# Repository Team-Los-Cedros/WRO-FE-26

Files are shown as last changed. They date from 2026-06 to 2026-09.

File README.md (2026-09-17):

# Proyecto Future Engineers - Team Los Cedros (WRO 2026)

Bienvenidos al repositorio oficial del **Team Los Cedros**, integrado por estudiantes del Colegio Los Cedros en Valera, Estado Trujillo, Venezuela. Aquí compartimos la documentación técnica, diseños de hardware, esquemas eléctricos y el software modular de nuestro vehículo autónomo para la World Robot Olympiad (WRO) 2026.

<p align="center">
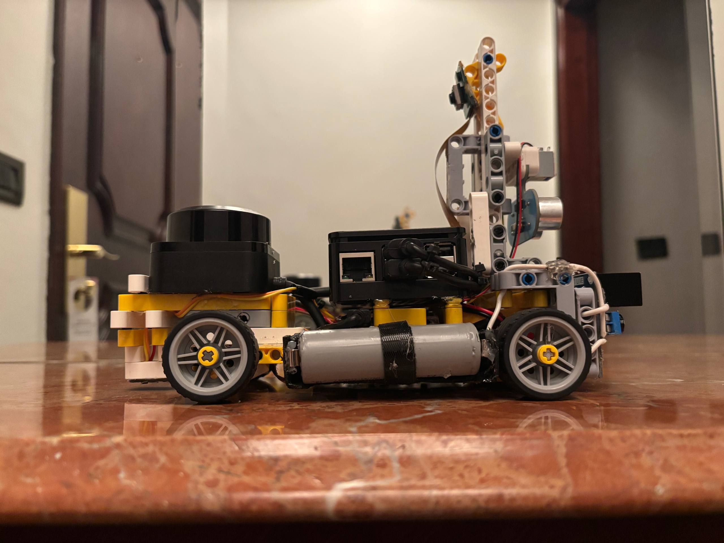
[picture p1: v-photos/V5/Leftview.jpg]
Vehiculo autonomo del Team Los Cedros, perfil izquierdo
  
</p>

---

## El robot en una página

#### Primero, en palabras simples

Es un **coche del tamaño de una hoja de papel que se conduce solo**. Hay que dejarlo en una pista cuadrada con paredes, apretarle un botón y alejarse: a partir de ahí nadie lo toca. Tiene que dar tres vueltas sin rozar las paredes y, en la prueba difícil, esquivar unos bloques de colores —**el rojo se pasa por la derecha y el verde por la izquierda**—, y al final volver a aparcar donde empezó.

Para lograrlo necesita tres cosas, que son las mismas que necesita una persona conduciendo: **ver** dónde está, **decidir** hacia dónde ir y **mover** el volante y el acelerador. Este documento explica cómo hace cada una de las tres, y —más importante— **cómo comprobamos que de verdad las hace**, porque casi todo lo que aquí se afirma tiene detrás una medición, no una suposición.

#### Y ahora, en términos técnicos

Un coche autónomo de **242 x 138 mm y 720 g** sobre chasis LEGO Technic, con dirección Ackermann. Lo gobiernan **dos cerebros**: una Raspberry Pi 5 que decide (visión, LiDAR y máquina de estados) y una Pico 2 que ejecuta con puntualidad garantizada (PWM, giroscopio y un watchdog que frena solo si la Pi calla). Ve el mundo con un **RPLiDAR C1** a 360°, una **Pi Camera Module 3** y cuatro sensores embarcados.

| Prueba | Estado | Evidencia |
| :--- | :--- | :--- |
| **Ronda Abierta** | Completa y grabada | [Ver el vídeo](https://youtu.be/zwYa40_EVPY) (06-09-2026) |
| **Ronda de Obstáculos** | El vehículo ejecuta la secuencia entera —sale del estacionamiento, esquiva los pilares por el lado que marca su color y vuelve al cuadrante de salida—, pero **la corrida limpia de tres vueltas sigue pendiente**. Las dos causas que lo impiden están identificadas y medidas. | [Las cinco corridas, una por una](video/video.md#ronda-cerrada) |

> Ese "pendiente" está escrito a propósito. Todo lo que este repositorio afirma se puede comprobar: cada corrida deja un CSV por barrido de LiDAR, y el marcador que usamos no es el registro interno del robot sino un verificador independiente que solo cuenta un pilar como superado cuando el eje trasero cruza su posición con separación positiva del lado obligatorio. Cuando el vídeo y el registro se contradicen, mandamos el vídeo.

## Dónde mirar

| Si busca... | Está en |
| :--- | :--- |
| **Movilidad y diseño mecánico** | [Sección 7 — Geometría de dirección](#7-geometría-de-dirección-y-movilidad-mecánica) — cinemática Ackermann, límites de giro calibrados en pista y el cálculo de torque con su margen. [Sección 7.5](#75-cadena-de-transmisión-del-motor-al-suelo) — la cadena de transmisión sin engranajes y por qué el límite del arranque lo pone el agarre del neumático, no el motor. [Sección 7.7](#77-materiales-y-manufactura-por-qué-el-chasis-dejó-de-imprimirse) — por qué el chasis dejó de imprimirse, con la tabla de materiales por pieza. [Secciones 3.2 y 3.3](#32-registro-fotográfico-de-la-evolución-e-iteración-geométrica-matriz-v1--v2--v3) — evolución V1→V3 y las seis vistas reglamentarias. CAD reproducible pieza a pieza en [`models/`](models/). |
| **Arquitectura de potencia y sensores** | [Sección 4 completa](#4-arquitectura-eléctrica-y-distribución-de-señales) — empieza por el [diagrama de bloques de señales](schemes/Diagrama_Bloques_Senales.svg). Alimentación desacoplada en tres etapas, pinout calibrado pin a pin y **consumo real medido con multímetro**, no estimado por hoja de datos. [Sección 4.5](#45-geometría-de-sensores-alcance-zonas-ciegas-y-autoecos) — desde dónde mira cada sensor, hasta dónde llega y **qué no puede ver**, incluidos los ecos del propio vehículo. [Sección 4.6](#46-integridad-de-señal-y-topología-de-cableado) — topología del cableado, tierra en estrella y por qué los dos buses I²C van separados. |
| **Arquitectura de software y estrategia de obstáculos** | [Sección 5 — Percepción y alto nivel](#5-capa-de-percepción-y-alto-nivel-raspberry-pi-5) — máquina de estados de carrera, evasión y estacionamiento. [Sección 5.3](#53-estrategia-de-navegación-justificada-por-rondas-geometría-del-campo) — la estrategia por rondas, deducida de la geometría del campo. [Sección 6](#6-capa-de-control-de-bajo-nivel-raspberry-pi-pico-2) — el firmware de tiempo real. |
| **Pensamiento sistémico y decisiones de ingeniería** | [Sección 3.4 — Trade-offs](#34-justificación-de-ingeniería-para-la-selección-de-componentes-y-arquitectura-de-sistemas-trade-offs) — por qué cada componente y qué se descartó. [Sección 8](#8-análisis-de-riesgos-y-registro-de-iteraciones) — interacción entre subsistemas y **cuatro casos de estudio con datos de pista**. [Sección 3.5](#35-línea-de-tiempo-del-proyecto-qué-se-intentó-qué-midió-y-qué-cambió-por-eso) — la línea de tiempo de las trece versiones y el punto de inflexión del proyecto. [Sección 9](#9-estado-actual-y-trabajo-pendiente) — lo que falta, y lo que se descartó midiendo. |
| **Reproducibilidad** | Tres documentos encadenados: [`BOM.md`](BOM.md) qué comprar → [`ENSAMBLAJE.md`](ENSAMBLAJE.md) cómo montarlo, con la comprobación que cierra cada etapa → [`INSTALACION.md`](INSTALACION.md) cómo dejar las dos placas en este mismo estado. Y [`CHANGELOG.md`](CHANGELOG.md), con los hashes de commit de cada hito. La documentación se comprueba sola: [`verificar_docs.py`](src/pi5/herramientas/verificar_docs.py) busca enlaces rotos, anclas muertas y los caracteres de control invisibles que rompen una formula sin que se vea. |
| **El código que corre hoy** | [`src/pi5/ronda_curvas/`](src/pi5/ronda_curvas/) en la Raspberry Pi 5 y [`src/pico/`](src/pico/) en la Pico 2. Lo archivado está separado a propósito en `legacy/`. |

---

### Índice por criterio de evaluación

Este índice está ordenado según los **cinco criterios de la rúbrica de documentación de WRO Future Engineers 2026**, para que cada uno pueda evaluarse sin reconstruirlo leyendo el documento entero. El índice estructural, sección por sección, está justo debajo.

#### 1 · Movilidad y diseño mecánico
*Chasis, dirección, transmisión, razonamiento par/velocidad y estabilidad mecánica.*

* [7.1 Cinemática Ackermann y calibración real](#71-cinemática-del-sistema-de-dirección-ackermann-y-calibración-real) — la geometría del tren delantero, medida sobre el prototipo.
* [7.3 Límites angulares calibrados](#73-límites-angulares-calibrados-y-protección-mecánica) — por qué el rango de giro **no** es simétrico, con evidencia fotográfica.
* [7.4 Cálculo de torque y fuerza de tracción](#74-análisis-de-ingeniería-cálculo-matemático-de-torque-y-fuerza-de-tracción) — el margen de $2.18\times$ sobre la masa real de $720\,\text{g}$.
* [7.5 Cadena de transmisión: del motor al suelo](#75-cadena-de-transmisión-del-motor-al-suelo) — relación $1:1$ sin engranajes, curva PWM→velocidad medida y **por qué el límite del arranque lo pone el agarre, no el motor**.
* [7.6 Envolvente de giro medida con marcadores](#76-envolvente-de-giro-medida-con-marcadores) — los radios no se calcularon: se dibujaron.
* [7.7 Materiales y manufactura](#77-materiales-y-manufactura-por-qué-el-chasis-dejó-de-imprimirse) — por qué el chasis dejó de imprimirse, con la tabla de material por pieza.
* [3.1 Cuadro comparativo de evolución V1→V5](#31-cuadro-comparativo-avanzado-de-evolución-e-iteración-técnica) · [CAD reproducible](models/)

#### 2 · Arquitectura de energía y sensores
*Alimentación, consumo, selección y ubicación de sensores, calibración y diagramas.*

* [4.1 Red de distribución de energía](#41-red-de-distribución-de-energía-alimentación) — tres etapas desacopladas, con el diagrama de cableado.
* [4.2 Catálogo de componentes y justificación](#42-catálogo-de-componentes-y-justificación-de-selección) — qué se eligió, dónde va montado y **el método de calibración de cada sensor**.
* [4.3 Mapa de conexiones calibrado (pinout)](#43-mapa-de-conexiones-calibrado-pinout) — pin a pin.
* [4.4 Presupuesto de consumo y autonomía](#44-presupuesto-de-consumo-energético-y-gestión-de-corriente) — **medido con multímetro**, no estimado por hoja de datos.
* [4.5 Geometría de sensores: alcance, zonas ciegas y autoecos](#45-geometría-de-sensores-alcance-zonas-ciegas-y-autoecos) — desde dónde mira cada sensor y **qué no puede ver**.
* [4.6 Integridad de señal y topología de cableado](#46-integridad-de-señal-y-topología-de-cableado) — tierra en estrella, calibres y aislamiento de los buses I²C.
* [10. Métodos de calibración](#10-métodos-de-calibración) — **los diez procedimientos**, en orden de ejecución y repetibles por un tercero.

#### 3 · Arquitectura de software y estrategia ante obstáculos
*Modularidad, máquinas de estado, seguimiento de carril, lógica de obstáculos y algoritmos.*

* [5.1 Orquestación y arranque autónomo](#51-orquestación-del-sistema-y-demonio-de-arranque-autónomo) — con el diagrama de flujo del sistema.
* [5.2 Estructura modular del script de carrera](#52-estructura-modular-del-script-de-carrera-fragmentos-clave) — la máquina de estados, en diagrama y en código.
* [5.3 Estrategia de navegación por rondas](#53-estrategia-de-navegación-justificada-por-rondas-geometría-del-campo) — deducida de la geometría del campo, con la FSM de evasión.
* [5.4 Parámetros de control y proceso de ajuste](#54-parámetros-de-control-y-proceso-de-ajuste) — qué se tocó y contra qué medida.
* [5.5 Reconocimiento de pilares por red neuronal](#55-reconocimiento-de-pilares-por-red-neuronal-acelerador-hailo) — el acelerador Hailo, el dataset y qué sustituye exactamente.
* [6. Capa de control de bajo nivel (Pico 2)](#6-capa-de-control-de-bajo-nivel-raspberry-pi-pico-2) — el firmware de tiempo real y la integración inercial.
* [11. Los algoritmos, explicados uno por uno](#11-los-algoritmos-explicados-uno-por-uno) — control proporcional, *pure pursuit*, odometría, conteo de vueltas, FSM y *watchdog*, cada uno **en lenguaje llano y en detalle técnico**.

#### 4 · Pensamiento sistémico y decisiones de ingeniería
*Interacción entre subsistemas, restricciones, compensaciones, iteración y riesgos.*

* [3.4 Trade-offs de selección](#34-justificación-de-ingeniería-para-la-selección-de-componentes-y-arquitectura-de-sistemas-trade-offs) — por qué cada componente y **qué se descartó**.
* [3.5 Línea de tiempo del proyecto](#35-línea-de-tiempo-del-proyecto-qué-se-intentó-qué-midió-y-qué-cambió-por-eso) — qué se intentó, qué se midió y qué cambió por eso.
* [8.1 Interacción entre subsistemas](#81-interacción-entre-subsistemas-pensamiento-sistémico) — cómo se acoplan las capas.
* [8.2](#82-caso-de-estudio-depuración-de-la-ronda-cerrada-con-evidencia-de-pista-close2_roundpy) · [8.3](#83-caso-de-estudio-reactivación-de-la-ronda-cerrada-modular-con-evidencia-cuantitativa-2026-08-27) · [8.4](#84-caso-de-estudio-gauntlet-de-6-pilares-asistencia-de-esquina-y-el-límite-de-la-reactividad-pura-2026-08-28) · [8.5](#85-diseño-e-implementación-desempate-de-esquina-simétrica-con-memoria-persistente-2026-08-28-continuación) — **cuatro casos de estudio con datos de pista**.
* [9. Estado actual y trabajo pendiente](#9-estado-actual-y-trabajo-pendiente) — lo que falta, y **lo que se descartó midiendo** (9.3).

#### 5 · Reproducibilidad y calidad del repositorio
*Estructura, historial de commits, README, archivos CAD/cableado/código y reproducibilidad.*

* [0. Estado actual del hardware](#0-estado-actual-del-hardware-última-revisión-17-09-2026) — el montaje que compite (V5), en una tabla.
* [2. Anatomía del repositorio](#2-anatomía-del-repositorio) — qué hay en cada carpeta y por qué.
* [3.3 Las capturas reglamentarias del vehículo](#33-galería-de-inspección-técnica-obligatoria-las-6-capturas-reglamentarias)
* Cadena de reproducción: [`BOM.md`](BOM.md) qué comprar → [`ENSAMBLAJE.md`](ENSAMBLAJE.md) cómo montarlo → [`INSTALACION.md`](INSTALACION.md) cómo dejar las dos placas en este estado.
* [`CHANGELOG.md`](CHANGELOG.md) — versionado con los hashes de commit de cada hito · [`video/video.md`](video/video.md) — las corridas en vídeo.
* [`verificar_docs.py`](src/pi5/herramientas/verificar_docs.py) — la documentación se comprueba sola: enlaces rotos, anclas muertas y finales de línea.
* [12. Glosario](#12-glosario) — cada término técnico del documento, explicado en una línea.

---

### Índice estructural

| # | Sección | | # | Sección |
| :---: | :--- | :---: | :---: | :--- |
| **0** | [Estado actual del hardware](#0-estado-actual-del-hardware-última-revisión-17-09-2026) | | **5** | [Percepción y alto nivel (Pi 5)](#5-capa-de-percepción-y-alto-nivel-raspberry-pi-5) |
| **1** | [Introducción y equipo](#1-introducción-y-equipo) | | **6** | [Control de bajo nivel (Pico 2)](#6-capa-de-control-de-bajo-nivel-raspberry-pi-pico-2) |
| **2** | [Anatomía del repositorio](#2-anatomía-del-repositorio) | | **7** | [Geometría de dirección y movilidad](#7-geometría-de-dirección-y-movilidad-mecánica) |
| **3** | [Diseño evolutivo e iteración](#3-diseño-evolutivo-y-ciclos-de-iteración) | | **8** | [Riesgos y registro de iteraciones](#8-análisis-de-riesgos-y-registro-de-iteraciones) |
| **4** | [Arquitectura eléctrica y señales](#4-arquitectura-eléctrica-y-distribución-de-señales) | | **9** | [Estado actual y trabajo pendiente](#9-estado-actual-y-trabajo-pendiente) |
| **10** | [Métodos de calibración](#10-métodos-de-calibración) | | **11** | [Los algoritmos, uno por uno](#11-los-algoritmos-explicados-uno-por-uno) |
| **12** | [Glosario](#12-glosario) | | | |

**Documentos que acompañan a este README:** [`BOM.md`](BOM.md) · [`ENSAMBLAJE.md`](ENSAMBLAJE.md) · [`INSTALACION.md`](INSTALACION.md) · [`CHANGELOG.md`](CHANGELOG.md) · [`video/video.md`](video/video.md)

---

## 0. Estado Actual del Hardware (última revisión: 17-09-2026)

El robot cambió en siete puntos respecto a la primera versión documentada en este README. Cada cambio se detalla en su sección; esta tabla existe para que no haya que reconstruirlo leyendo el documento entero.

| Qué cambió | Antes | Ahora | Dónde se detalla |
| :--- | :--- | :--- | :--- |
| **Cerebro de alto nivel** | Raspberry Pi 3B | **Raspberry Pi 5** (migrado el 03-09-2026) | 4.2 y 5 |
| **Soporte del LiDAR** | Sin mástil documentado | **Mástil** con el plano de barrido a 69 mm del piso; se enmascara el sector 140-213° que él mismo ocupa | 4.2 |
| **Medida trasera** | Ninguna | **Ultrasonido HC-SR04** en `GP14`/`GP15`, único sensor que ve hacia atrás | 4.2 y 4.3 |
| **Sensor de color de piso** | TCS3472 bajo el chasis | **Sigue montado, y se mudó al frente.** Se desconectó durante la migración a la Pi 5, se volvió a conectar, y en el montaje actual va por delante del eje delantero en vez de bajo el chasis. Hoy es una de las tres evidencias del sentido, junto a la cámara y la asimetría de paredes | 4.2 y 5.3-C |
| **Arranque** | Dos botones (uno por ronda) | **Un solo botón en `GPIO 21`** | 4.2 y 4.3 |
| **Acelerador de inferencia** | Ninguno; la detección de pilares era HSV en CPU | **Raspberry Pi AI HAT+ de 26 TOPS** (Hailo-8) sobre la Pi 5. Sustituye **solo** el reconocimiento de pilares; las líneas de pista y el LiDAR siguen igual | 4.2 y 5.5 |
| **Posición de la Pico 2** | Sobre el chasis, al mismo nivel que el resto | **Bajo la Raspberry Pi 5**, en el piso del chasis. Libera la planta superior para el HAT y acorta el cableado a los actuadores | 0 y 4.6 |

---

### Montaje actual (V5)

La V5 no toca el chasis ni la geometría: **reorganiza la planta de cómputo** para hacerle sitio a un acelerador de inferencia. Son dos cambios, y el segundo existe por el primero.

* **Se añadió un Raspberry Pi AI HAT+ de 26 TOPS (Hailo-8) sobre la Raspberry Pi 5.** Un HAT ocupa el conector de 40 pines y el espacio inmediatamente encima de la placa, así que exige que nada más compita por esa planta.
* **La Raspberry Pi Pico 2 bajó al piso del chasis, debajo de la Pi 5.** Antes iba al mismo nivel. Además de liberar la planta superior, el cambio acorta el recorrido de las líneas que van a los actuadores, que son las que conviven con el ruido de conmutación del motor (sección 4.6).

La colocación de los sensores es la misma que se fijó en la V4 y sigue vigente por las mismas razones: **adelantar la percepción**.

* **La cámara va en un mástil trasero**, desde donde mira hacia adelante por encima de todo el vehículo, y el LiDAR va bajo, sobre el chasis y por delante. El mástil lleva también el ultrasonido, apuntando hacia atrás.
* **El sensor de color va adelantado**, por delante del eje delantero en vez de bajo el chasis. Leer la línea antes de pisarla da margen de reacción; leerla debajo solo avisa de que ya se cruzó.

| Frontal | Trasera |
| :---: | :---: |
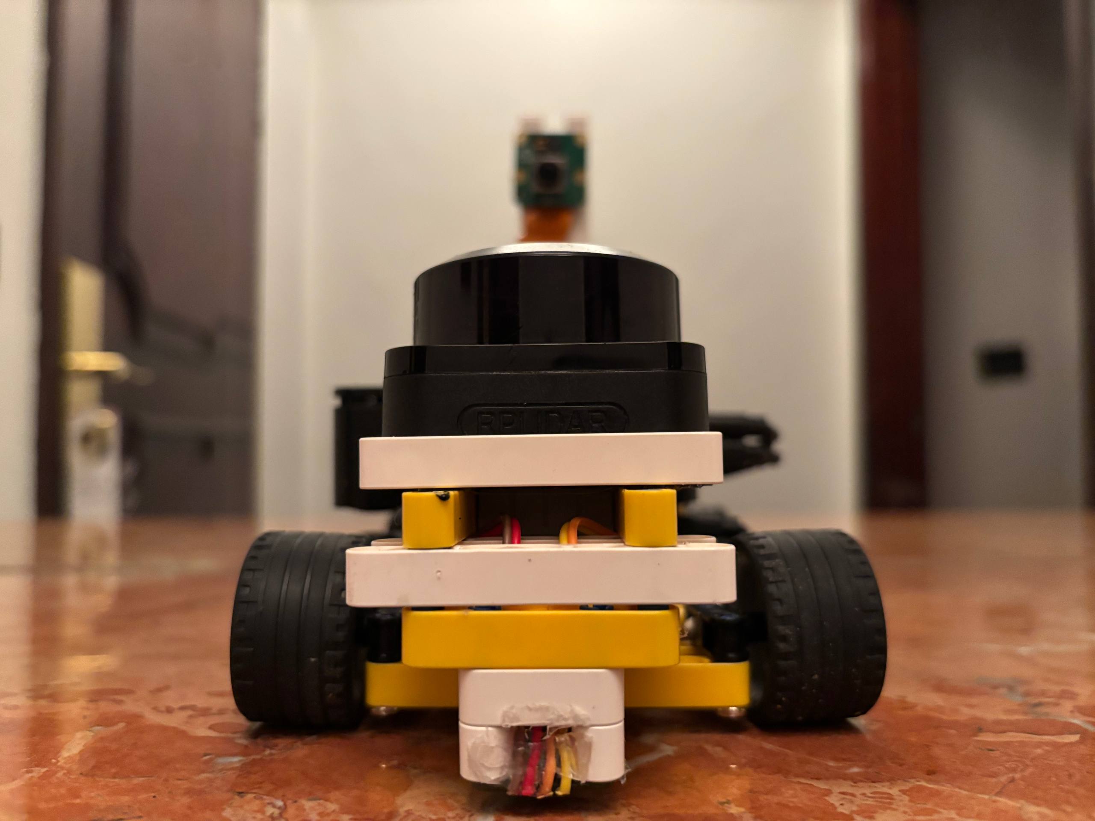
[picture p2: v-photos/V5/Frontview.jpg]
Vista frontal: el LiDAR es el extremo que va primero
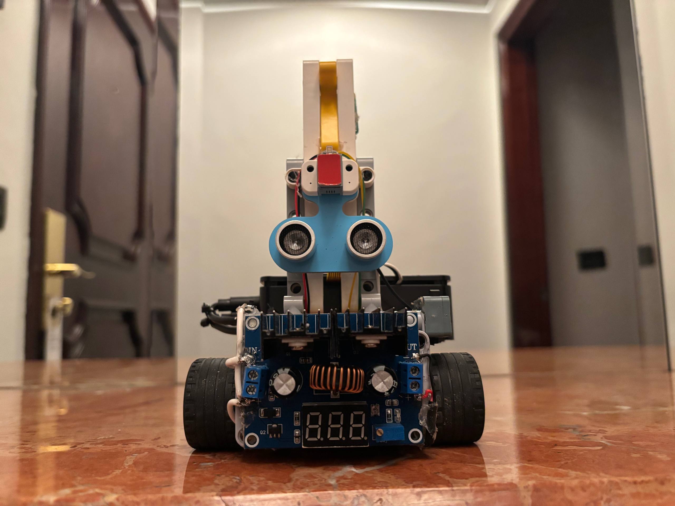
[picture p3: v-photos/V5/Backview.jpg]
Vista trasera: el mastil con la camara y el ultrasonido
|  |  |

| Perfil izquierdo | Perfil derecho |
| :---: | :---: |
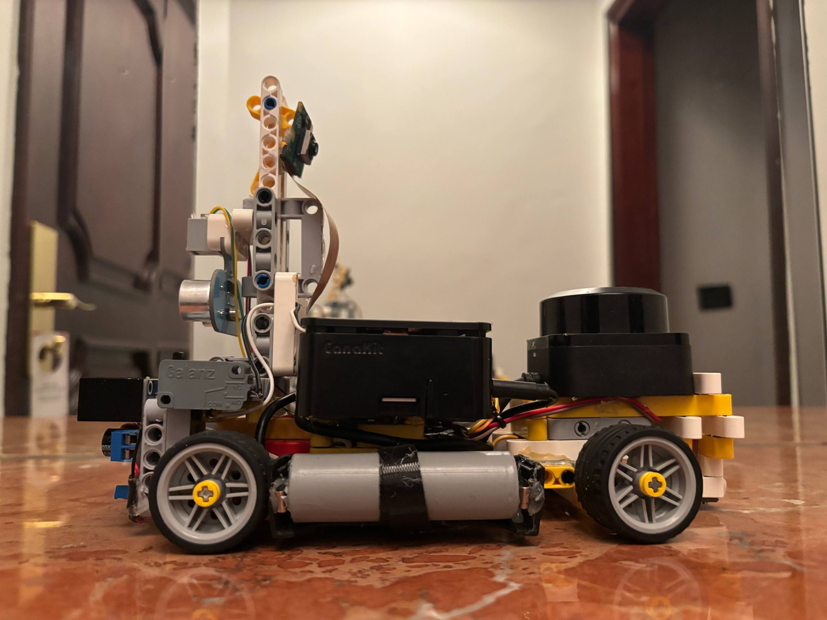
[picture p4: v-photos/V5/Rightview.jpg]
Perfil derecho del montaje actual
| Perfil izquierdo del montaje actual |  |

| Superior | Chasis con la Pico 2 reubicada |
| :---: | :---: |
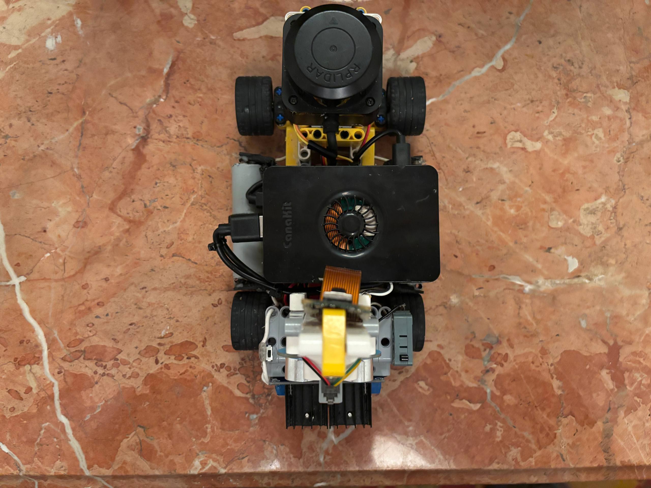
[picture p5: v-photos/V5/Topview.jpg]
Vista superior del montaje actual
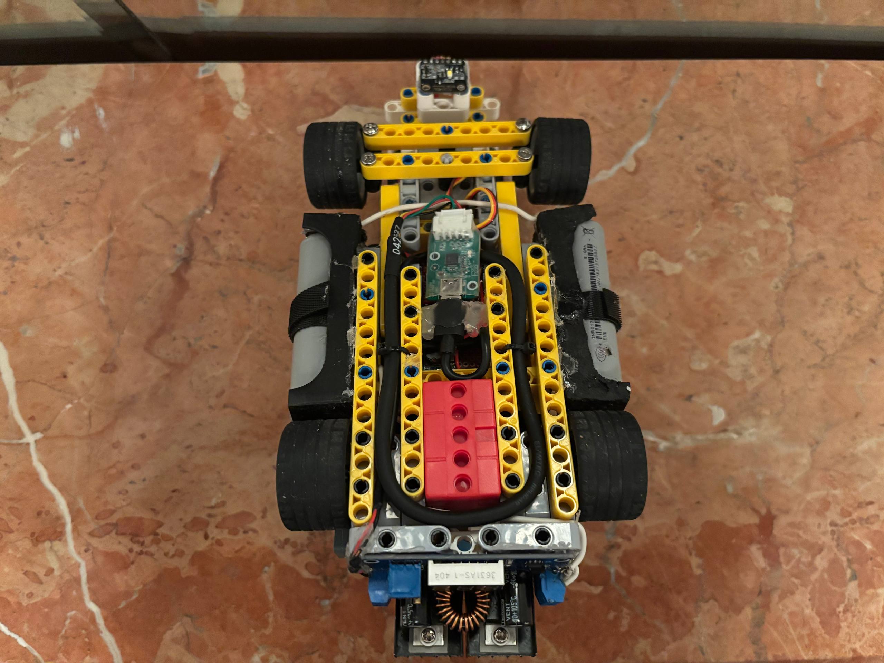
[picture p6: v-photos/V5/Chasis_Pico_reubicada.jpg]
Planta del chasis con la Pico 2 en su posicion nueva
|  |  |

#### Evidencia del cambio: la Pico 2 en su posición nueva

La placa perforada con la **Pico 2, el MPU6050 y el TB6612FNG** quedó montada en el piso del chasis. Estas tomas son la evidencia del montaje, y sirven además para verificar dos condiciones que el resto del documento da por sentadas: que la **IMU está alineada con el eje longitudinal** (sección 4.2) y que las tres piezas van **soldadas, no con *jumpers*** (sección 4.6).

| La placa dentro del chasis | Detalle: Pico 2, IMU y driver |
| :---: | :---: |
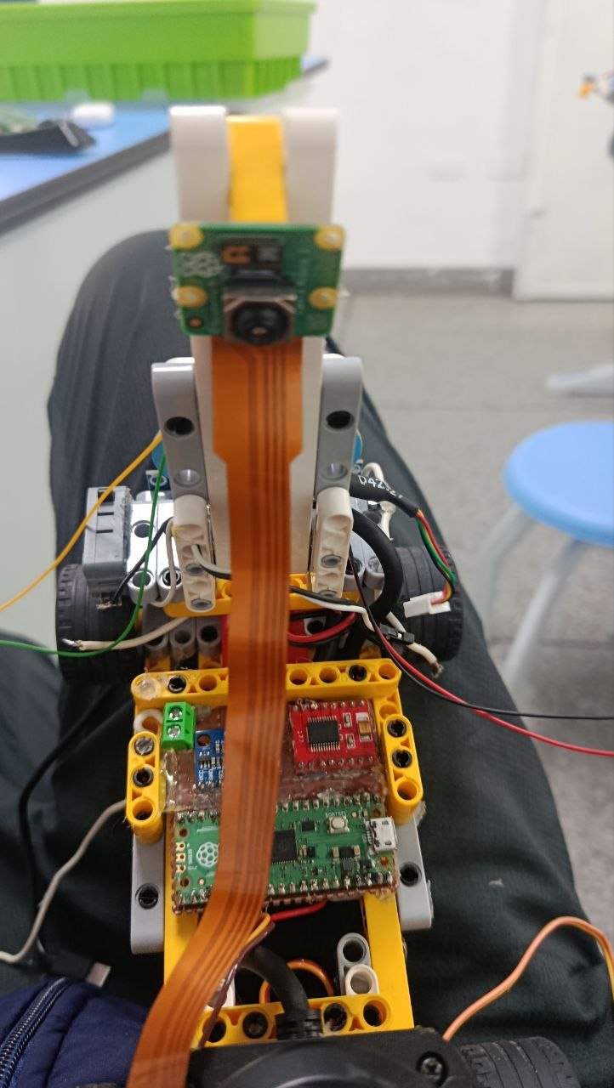
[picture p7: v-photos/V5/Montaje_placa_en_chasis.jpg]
Placa perforada montada en el piso del chasis, con el cable CSI subiendo al mastil
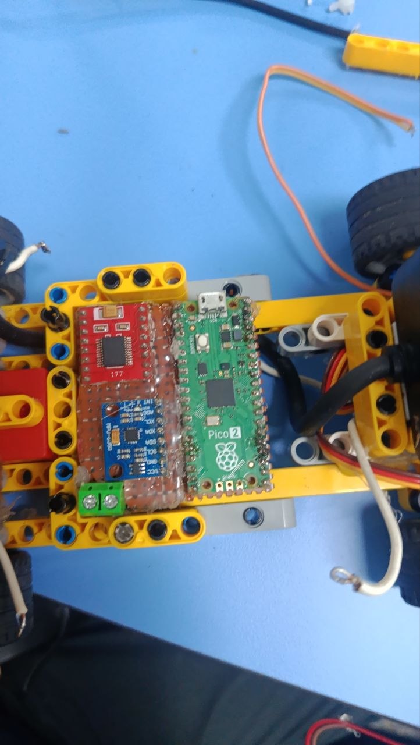
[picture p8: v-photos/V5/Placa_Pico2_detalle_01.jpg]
Detalle de la placa: TB6612FNG, MPU6050 y Pico 2
|  |  |

| Otro ángulo de la placa | La placa con el LiDAR al fondo |
| :---: | :---: |
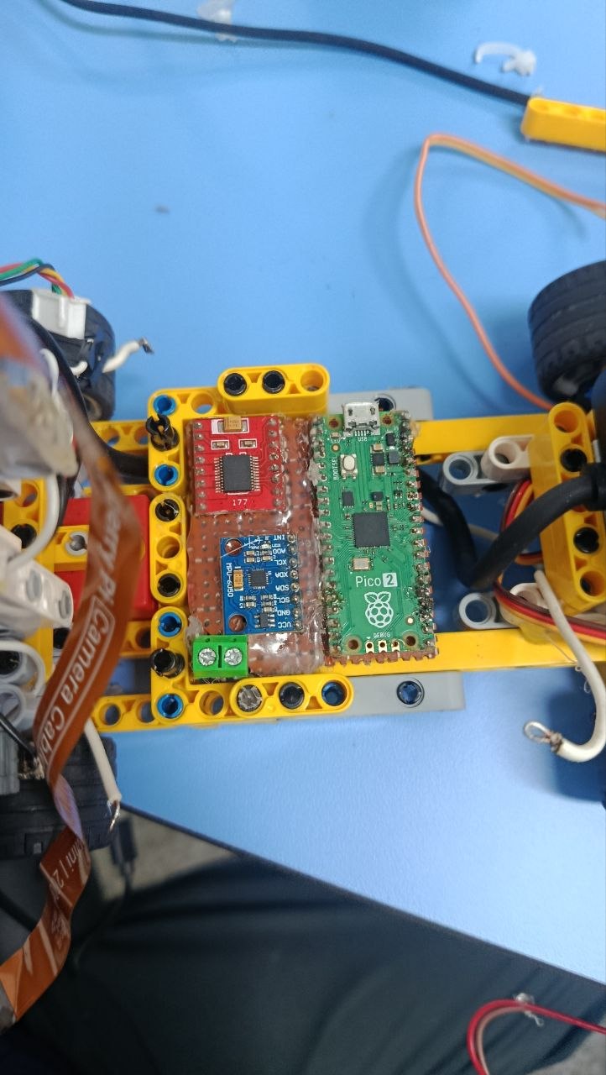
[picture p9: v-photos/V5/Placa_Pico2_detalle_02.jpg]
Segundo angulo de la placa perforada
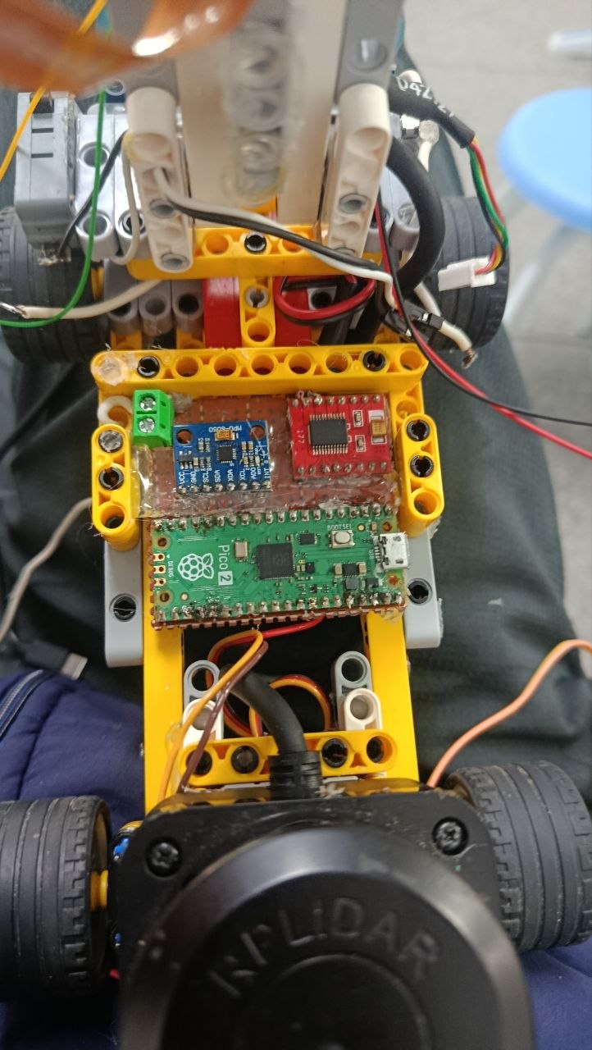
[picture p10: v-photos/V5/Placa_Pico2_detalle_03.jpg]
La placa perforada con el LiDAR visible al fondo
|  |  |

> Las medidas de la sección 7.6 —dimensiones del chasis y radios de giro trazados con marcadores— **siguen siendo válidas**: la V5 no cambió el chasis, la batalla, la vía ni los límites de dirección. Lo que cambió está por encima del chasis.

---

## 1. Introducción y Equipo

### 1.1 Foto del Equipo
<p align="center">
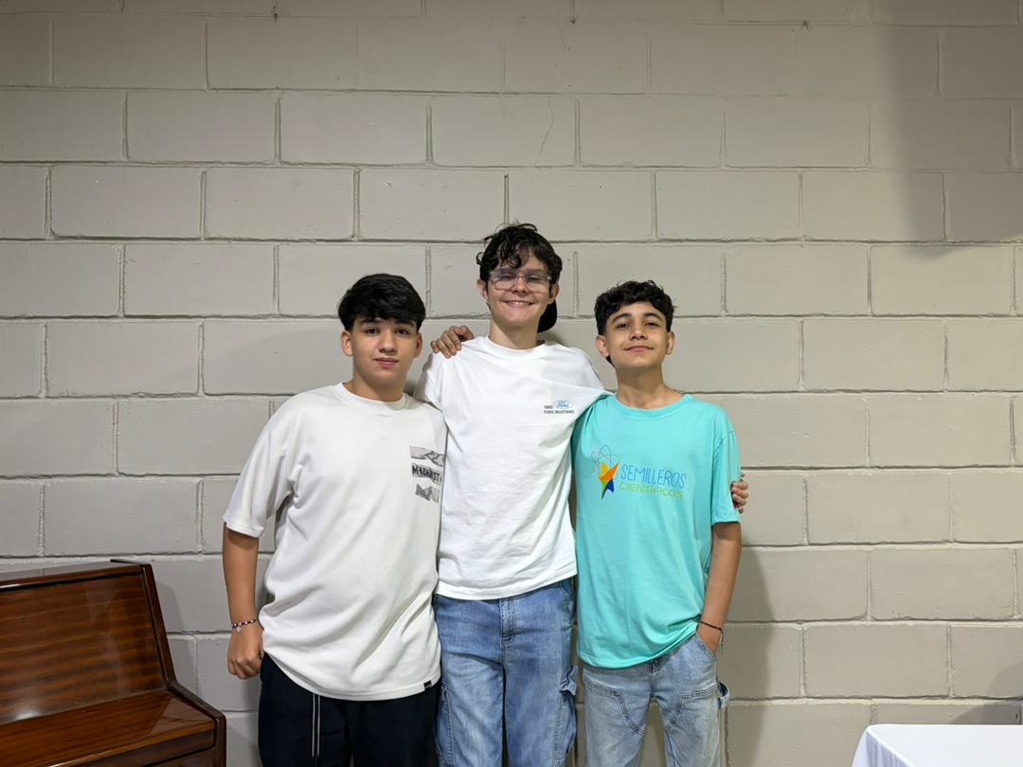
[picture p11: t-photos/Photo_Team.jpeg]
Team Los Cedros - WRO 2026
  
</p>

### 1.2 Integrantes y Roles
| Integrante | Rol / Especialidad | Contribución Principal |
| :--- | :--- | :--- |
| **Daniel David Díaz Rivas** | Líder de Proyecto / Hardware | Diseño de chasis y distribución electrónica. |
| **Carlos David Díaz Rivas** | Desarrollador de Software | Programación de la lógica de alto nivel en Raspberry Pi (3B primero, Pi 5 desde el 03-09-2026). |
| **Carlos Santiago Pinto Abreu** | Especialista en Control | Firmware y calibración inercial en Raspberry Pi Pico 2. |

---

## 2. Anatomía del Repositorio

Estructura modular y limpia del proyecto conforme a las regulaciones oficiales de la WRO:

```

├── src/                          # Código fuente de la arquitectura distribuida
│   ├── pico/                     # Firmware embebido (MicroPython - Raspberry Pi Pico 2)
│   │   ├── main.py               # Bucle principal de control en tiempo real y actuadores
│   │   ├── protocolo_seguro.py   # Valida consignas y modela el watchdog de 500 ms
│   │   └── Mpu6050.py            # Driver I2C standalone para el sensor inercial MPU6050
│   ├── pi5/                      # Scripts de alto nivel (Python 3 - Raspberry Pi 5) -- CODIGO VIVO
│   │   ├── deploy.sh             # Despliegue atomico "create only": nunca mezcla sobre una instalacion previa
│   │   ├── MEDICIONES_20260906.md # Medidas de banco del chasis, la bahia y la velocidad
│   │   ├── comun/                # Driver del LiDAR compartido por los tres cerebros
│   │   ├── legacy/               # Implementaciones históricas de Pi 5 (no activas)
│   │   │   ├── ronda_nueva/      # Cerebro modular archivado, con configuración y pruebas
│   │   │   └── ronda_cerrada/    # Cerebro previo archivado
│   │   ├── ronda_abierta/        # Open Challenge en un solo archivo auditable
│   │   └── herramientas/         # 15 diagnosticos de banco (ver seccion 2.2)
│   └── pi3B/                     # Scripts de la Raspberry Pi 3B -- ARCHIVADO (ver seccion 4.2)
│       ├── controlador_inicio.py # Orquestador central (Ejecutado como servicio del sistema OS)
│       ├── deploy.sh             # Copia los .py de carrera planos a /home/pi/
│       ├── comun/                # Drivers compartidos por ambas rondas
│       │   ├── lidar_driver.py   # Driver: protocolo binario RPLIDAR C1
│       │   ├── lidar_geometria.py # Procesador: paredes y clustering ABD
│       │   ├── enlace_pico.py    # Canal serial con la Pico 2 (consignas + telemetria IMU)
│       │   └── registro_metricas.py # Logger CSV de telemetria por ciclo (error lateral, angulo, heading)
│       ├── ronda_abierta/
│       │   └── ronda_abierta.py  # Reutiliza comun/: centrado proporcional + parqueo
│       ├── ronda_cerrada/        # FSM de navegación/evasión de la Ronda Cerrada
│       │   ├── ronda_cerrada.py  # Punto de entrada (importa comun/ + los 4 siguientes)
│       │   ├── navegacion.py     # Cerebro: máquina de estados de carrera/evasión/parqueo
│       │   ├── camara_driver.py  # Driver: adquisición de frames (Picamera2)
│       │   ├── vision.py         # Procesador: detección HSV de postes rojo/verde
│       │   ├── tracker.py        # Object persistence tracker del obstáculo activo
│       │   └── legacy/           # Versiones superadas (archivadas, no desplegar)
│       ├── prueba/               # Borradores nunca desplegados (distinto de legacy/, ver su README)
│       ├── requirements.txt      # Dependencias Python del entorno de la Pi 3B
│       └── wro_start.service     # Unidad systemd real para el arranque autónomo
├── models/                    # Modelos mecánicos: STL del chasis V1 (archivado) y CAD LEGO del V2
│   ├── Chasis-LEGO-V2/           # Archivo .io (BrickLink Studio), render y listado de piezas del chasis actual
│   └── V1/                       # STL, catálogo y guía de ensamblaje del chasis impreso archivado
├── t-photos/                     # Fotos de las jornadas de desarrollo del equipo
├── v-photos/                     # Las 6 capturas reglamentarias, fotos V1 vs V2 y componentes
│   ├── Componentes/               # Foto individual de cada componente electrónico usado
│   └── Ackermann/                 # Evidencia fotográfica de los límites de giro calibrados
├── video/                        # Enlace oficial del video de pista y borradores de prueba
├── schemes/                      # Diagrama de cableado y fotos de la placa perforada
├── README.md                      # Documentación técnica principal (este archivo)
├── BOM.md                         # Lista de materiales: qué comprar y para qué sirve cada pieza
├── ENSAMBLAJE.md                  # Manual de montaje físico, etapa a etapa y con su verificación
├── INSTALACION.md                 # Manual paso a paso para reproducir el entorno desde cero
└── CHANGELOG.md                   # Notas de versión por hito, referenciadas a commits reales

```

> **Nota de Software de Inicio:** `controlador_inicio.py` fue el orquestador maestro de la Raspberry Pi 3B, arrancado por `systemd`. En la Pi 5 el cerebro se lanza directamente (`python3 -m ronda_nueva.ronda_nueva`) y espera el botón de `GPIO 21`; las unidades `wro_start.service` y `wro_robot.service` están copiadas pero **deshabilitadas**, igual que en la 3B.

> **Reproducibilidad.** Reconstruir este vehículo desde cero son tres documentos encadenados: [`BOM.md`](BOM.md) dice qué comprar y por qué se eligió cada pieza, [`ENSAMBLAJE.md`](ENSAMBLAJE.md) cómo montarlo etapa por etapa con la comprobación que cierra cada una, e [`INSTALACION.md`](INSTALACION.md) cómo dejar la Raspberry Pi 5 y la Pico 2 en este mismo estado de software.

### 2.1 Historial de Versiones y Control de Cambios

El repositorio mantiene un historial de commits granular (70+ confirmaciones) que documenta el proceso real de ingeniería, no solo el resultado final. Los hitos principales, en orden cronológico:

| Etapa | Commits representativos | Qué cambió |
| :--- | :--- | :--- |
| **Estructura inicial** | `chore: crear estructura de carpetas oficiales para WRO 2026`, `docs: inicializar README.md` | Se define el esqueleto reglamentario del repositorio (`src/`, `v-photos/`, `schemes/`, etc.). |
| **Firmware base Pico 2** | `feat(pico2): script nativo en MicroPython`, `feat(control): implementar máquina de estados base`, `feat(pico): implementar parser serial no bloqueante` | Primera versión funcional del control de bajo nivel y protocolo serial Pi↔Pico. |
| **Integración de sensores** | `feat(pi5): implementar procesamiento crudo de bytes para rplidar`, `feat(pico): corregir mapeo de pines I2C de la IMU` | Se resuelven conflictos de canales PWM y se estabiliza la lectura del LiDAR y del giroscopio. |
| **Migración de chasis V1 → V2** | `Estructura base y hardware V2 en LEGO`, `justificar ventajas cinemáticas del chasis LEGO de 613g frente a impresión 3D` | Rediseño completo de la plataforma mecánica (ver sección 3). |
| **Corrección de calibración de dirección** | `Arreglo de angulo central del robot de 90 a 180 grados` → `Arreglo en equivocacion de angulo central` | Se probó un centro de servo a 180° y se revirtió a **90°** tras validar en pista que generaba error de alineación (ver sección 6 y 7.3 — el README refleja el valor vigente). |
| **Ronda Cerrada (en curso)** | `Añadimos codigos de Calibracion HSV para la ronda cerrada`, rama `dev-close_round` | Desarrollo activo del algoritmo de evasión de obstáculos con herramienta de calibración HSV dedicada. |

> **Nota de reproducibilidad:** Se puede auditar la evolución exacta de cualquier archivo con `git log --follow -p -- <archivo>`, por ejemplo `git log --follow -p -- src/pico/main.py` muestra el cambio de calibración del ángulo central documentado arriba.

> **Notas de lanzamiento:** El detalle de cada hito (con los hashes de commit exactos que lo componen) está en [`CHANGELOG.md`](CHANGELOG.md). Los hitos principales también están marcados como tags de git (`git tag`, o [ver Releases en GitHub](https://github.com/Team-Los-Cedros/WRO-FE-26/tags)).

---

## 3. Diseño Evolutivo y Ciclos de Iteración

El desarrollo de nuestro vehículo autónomo no fue un proceso lineal. Para alcanzar la estabilidad actual, el prototipo pasó por una transición crítica basada en datos experimentales de rendimiento y fallos mecánicos en pista

### 3.1 Cuadro Comparativo Avanzado de Evolución e Iteración Técnica

Para alcanzar la estabilidad operativa actual, el prototipo pasó por una transición crítica basada en datos experimentales de rendimiento dinámico, telemetría inercial y análisis de fallos mecánicos destructivos en pista:

> **El prototipo que compite es la V5.** Las cinco versiones cambiaron cosas distintas, y por eso se documentan por separado: el salto **V1 → V2** fue *mecánico* (chasis, masa, tracción y topología de potencia) y es el de esta tabla; el **V2 → V3** fue *electrónico* (Raspberry Pi 5, mástil del LiDAR, ultrasonido trasero y botón único); el **V3 → V4** fue de *colocación de sensores*, sin tocar el chasis; y el **V4 → V5** es de *cómputo* (acelerador Hailo de 26 TOPS y la Pico 2 reubicada bajo la Pi 5), también sin tocar el chasis. Los tres últimos están en la [sección 0](#0-estado-actual-del-hardware-última-revisión-17-09-2026), con las vistas del montaje que compite.

| Criterio Técnico | Prototipo Inicial (V1) | Rediseño Mecánico (V2) | Justificación de Ingeniería / Análisis de Fatiga |
| :--- | :--- | :--- | :--- |
| **Arquitectura Estructural** | Monocasco impreso en 3D (PLA / Filamento) | Chasis Híbrido de Vigas de Fricción LEGO | **Mitigación de Resonancia:** El filamento rígido transmitía las vibraciones mecánicas de alta frecuencia de los motores directo a la cámara, descalibrando el software de visión. El chasis LEGO absorbe el ruido vibracional por flexión elástica y permite reconfiguraciones geométricas inmediatas en boxes. |
| **Masa Inercial Global** | $\approx 800\,\text{g}$ (Diseño robusto impreso) | **613 gramos exactos** (Reducción del $23.37\%$) | **Optimización Dinámica:** Al remover casi una cuarta parte del peso total, se redujo drásticamente la inercia lineal ($I$). El servomotor requiere menor torque para vencer la fricción estática en las curvas de Ackermann, eliminando por completo el subviraje físico. |
| **Sistema de Visión** | Módulo Arducam 3 (Estructura Expuesta) | Raspberry Pi Camera Module 3 Integrada | **Análisis de Riesgos:** El hardware V1 sufrió una falla crítica por impacto directo contra el perímetro. En la V2 se rediseñó el centro de masa retrasando el soporte óptico, protegiendo el sensor y aprovechando los drivers nativos a nivel de kernel de la Pi 3B. |
| **Eficiencia de Tracción** | Llantas rígidas de plástico (Bajo agarre) | Neumáticos de Caucho LEGO ($36\,\text{mm}$ diámetro) | **Transferencia de Potencia:** Las ruedas plásticas patinaban al acelerar bruscamente a PWM máximos, disipando energía por calor. El compuesto de caucho incrementa el coeficiente de fricción ($\mu_e \approx 0.85$), garantizando un grip total sin derrapes laterales. |
| **Topología de Potencia** | Regulador único lineal (Sujeto a picos) | Desacoplamiento por etapas (XL4016 + XL1509) | **Blindaje Electrónico:** La conmutación del motor causaba caídas de tensión lógicas (*brownouts*). Al meter el **XL4016 de $8.0\,\text{A}$** dedicado a la Pi 3B, la etapa de control trabaja fría y con un margen de seguridad del **$73.25\%$**. |

### 3.2 Registro Fotográfico de la Evolución e Iteración Geométrica (Matriz V1 / V2 / V3)

Para evidenciar la transformación del vehículo y el rediseño de los tres ejes espaciales, se presenta el registro fotográfico emparejado de las tres iteraciones. Entre la V2 y la V3 el chasis no cambió: lo que cambió es lo que va montado encima, y por eso las siluetas se parecen mientras la electrónica no:

| Vista | V1 — ≈800 g | V2 — 613 g | **V3 — actual** |
| :---: | :---: | :---: | :---: |
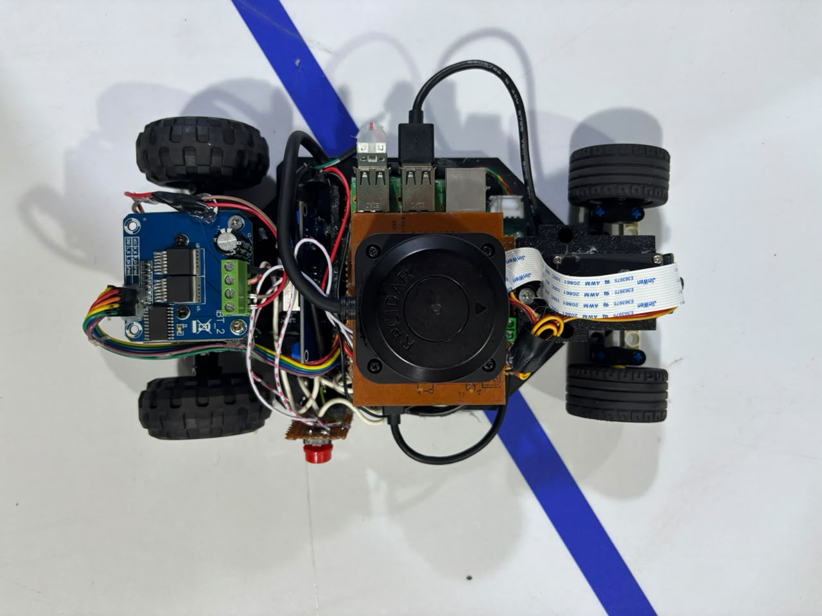
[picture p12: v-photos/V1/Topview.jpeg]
V1 Superior
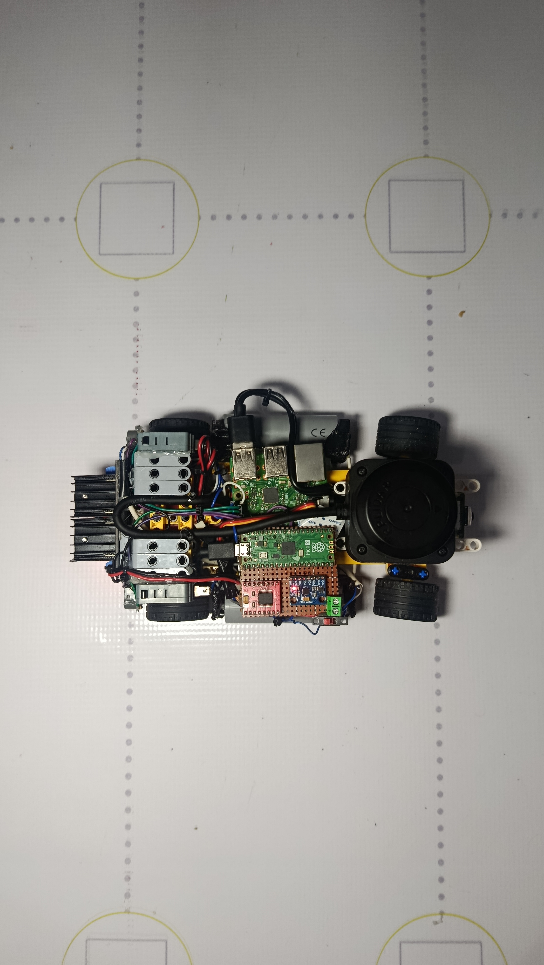
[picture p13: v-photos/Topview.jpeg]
V2 Superior
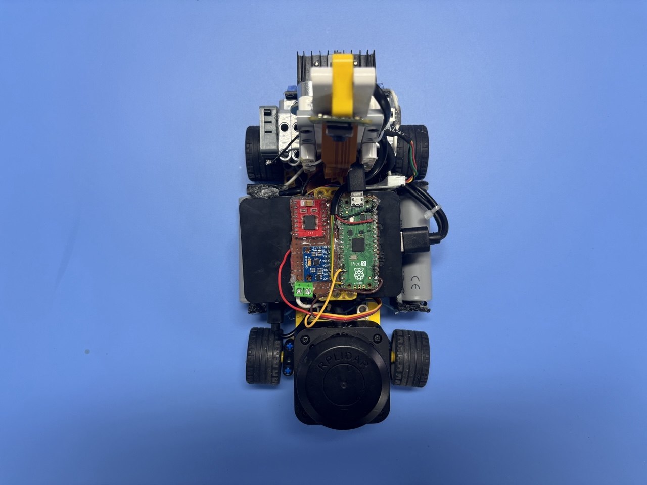
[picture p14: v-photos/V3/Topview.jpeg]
V3 Superior
| **Superior** |  |  |  |
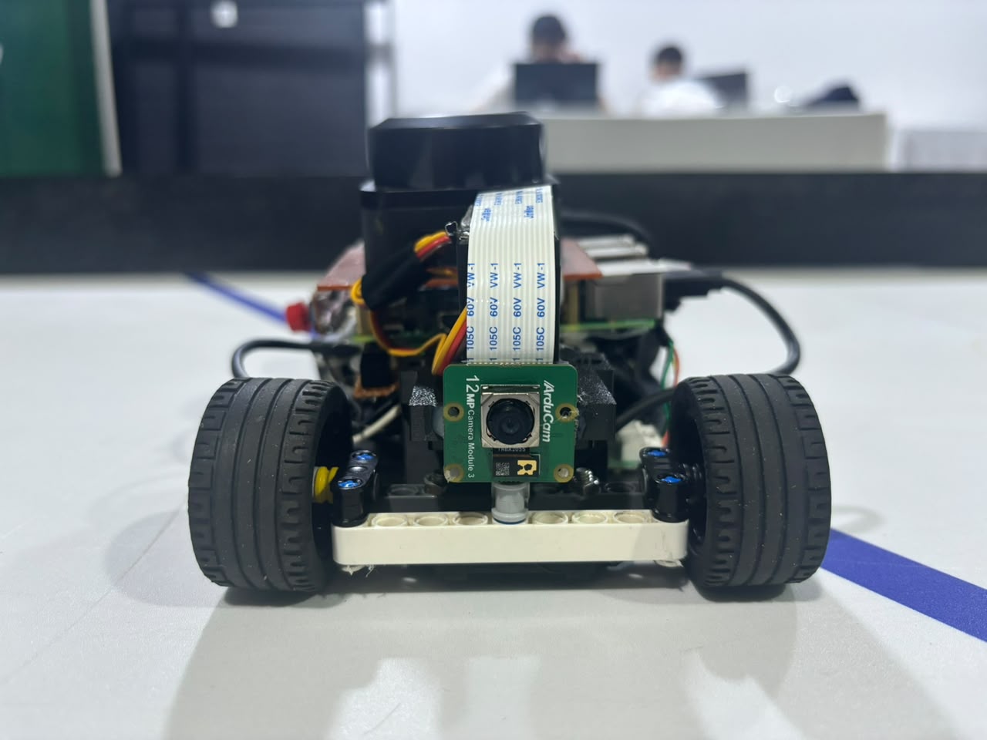
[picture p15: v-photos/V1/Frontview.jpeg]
V1 Frontal
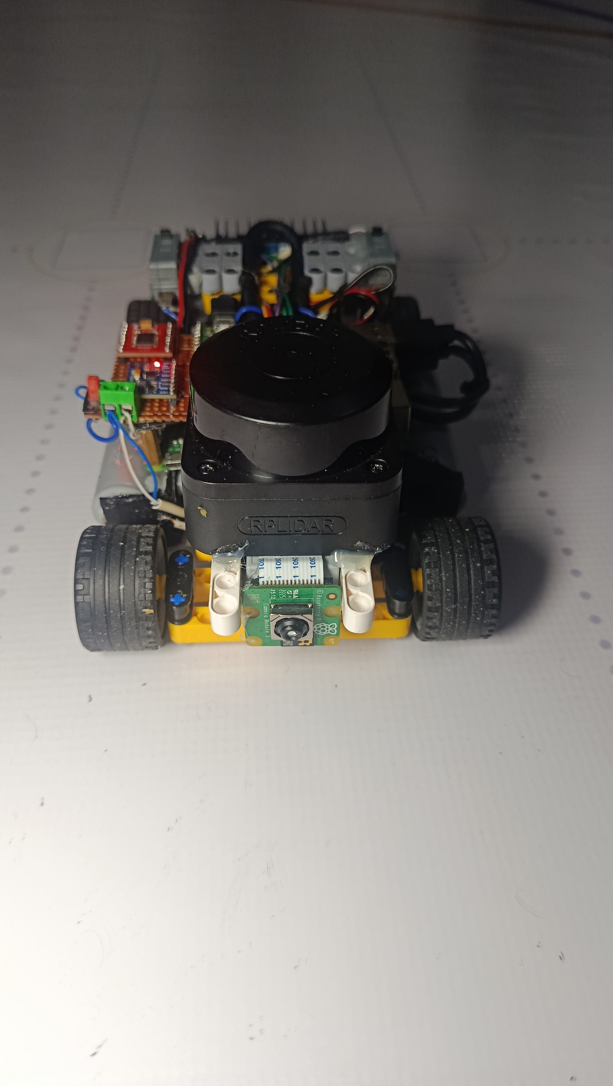
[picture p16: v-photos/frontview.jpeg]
V2 Frontal
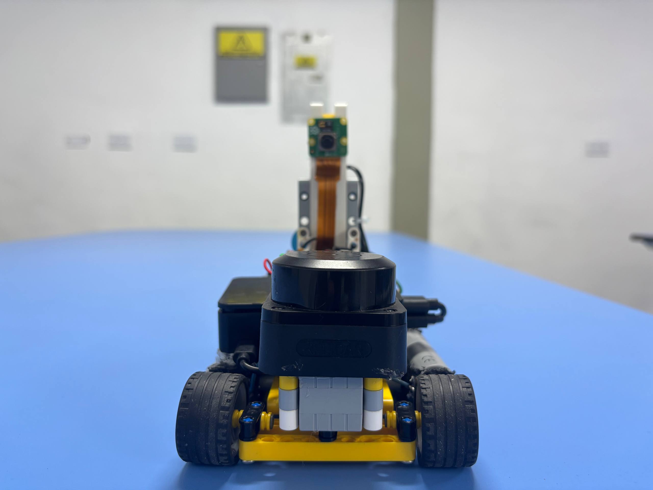
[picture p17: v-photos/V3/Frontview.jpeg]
V3 Frontal
| **Frontal** |  |  |  |
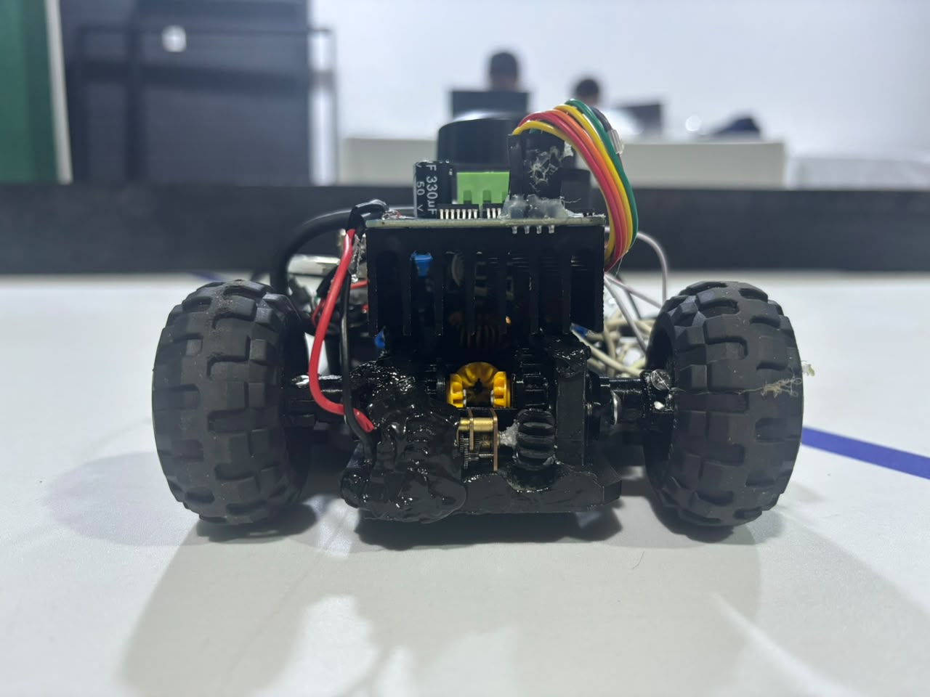
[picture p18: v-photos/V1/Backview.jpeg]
V1 Trasera
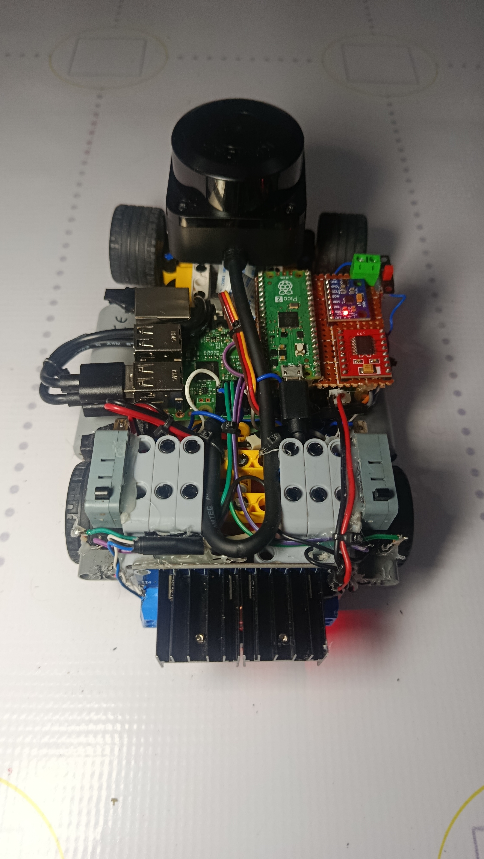
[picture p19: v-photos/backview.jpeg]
V2 Trasera
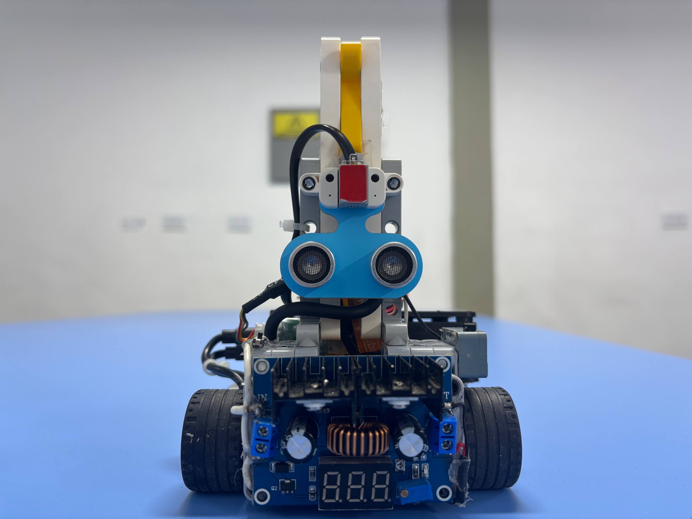
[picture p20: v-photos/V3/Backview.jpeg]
V3 Trasera
| **Trasera** |  |  |  |
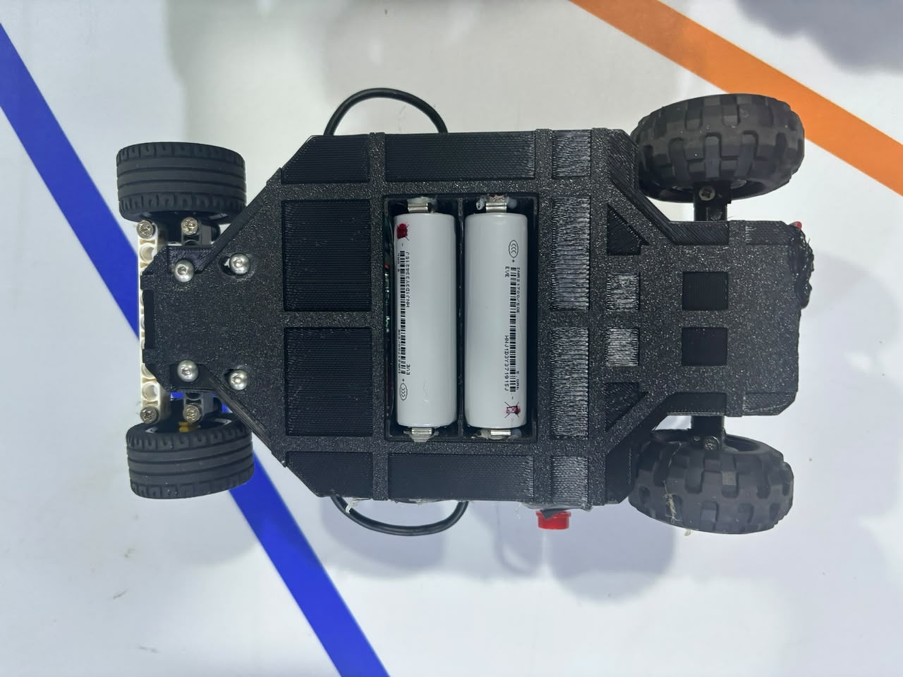
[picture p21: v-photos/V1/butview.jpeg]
V1 Inferior
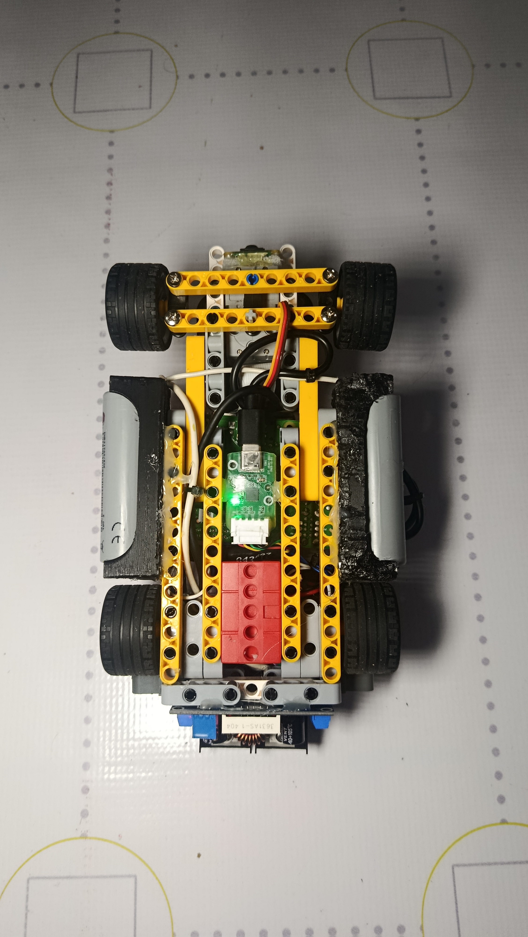
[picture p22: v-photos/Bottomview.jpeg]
V2 Inferior
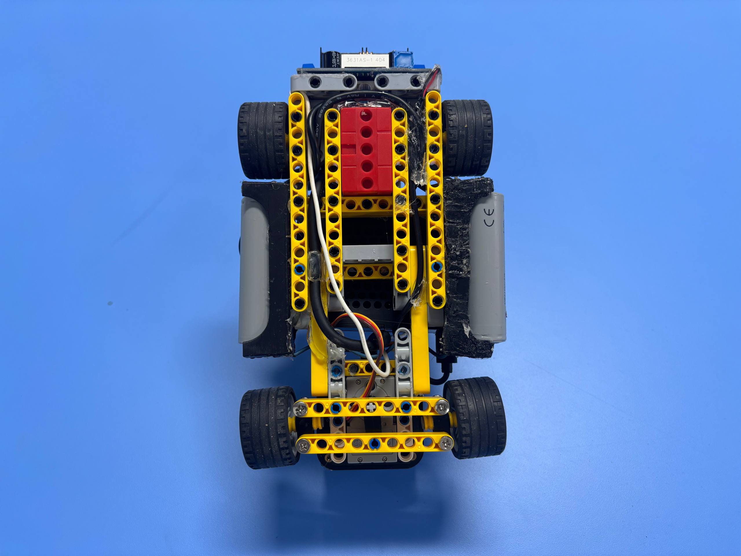
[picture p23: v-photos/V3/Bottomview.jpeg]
V3 Inferior
| **Inferior** |  |  |  |
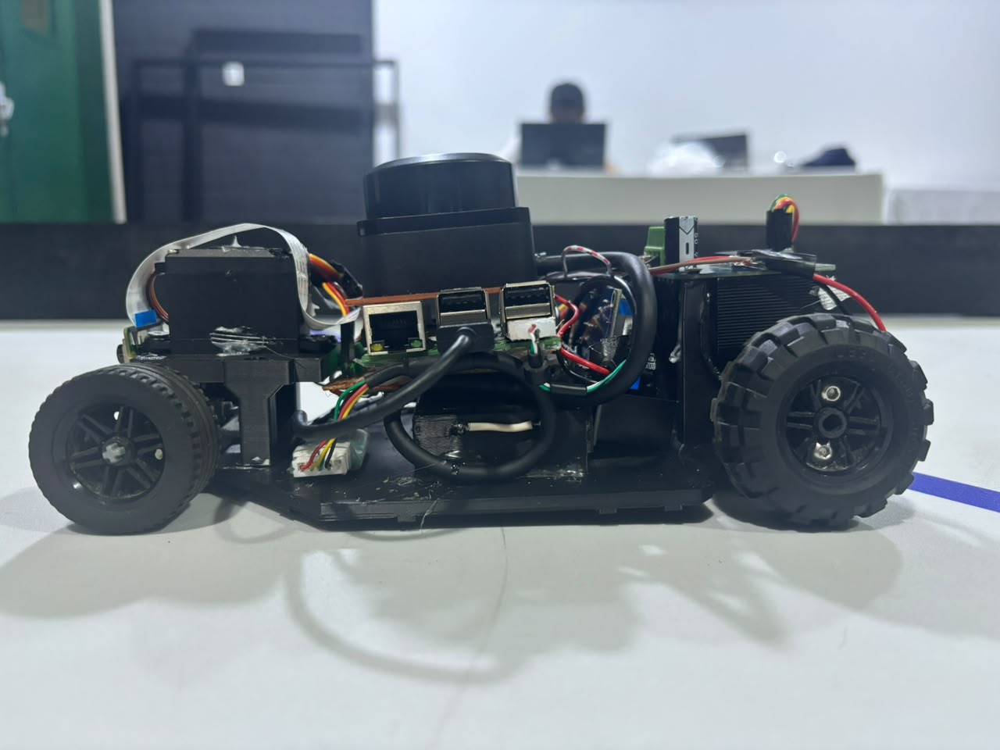
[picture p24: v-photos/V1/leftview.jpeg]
V1 Izquierda
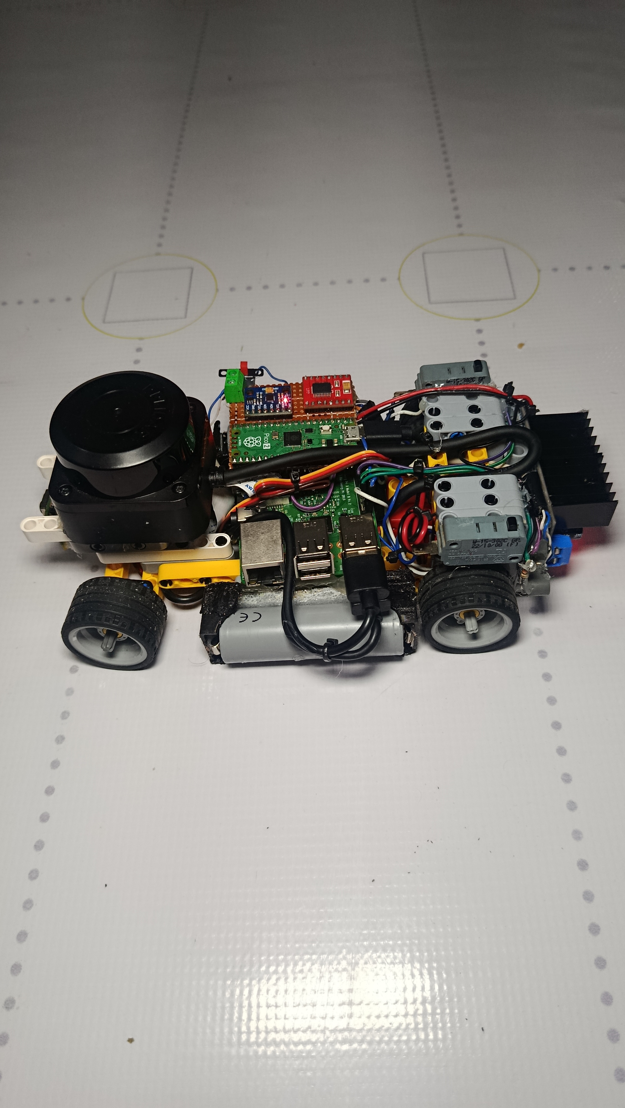
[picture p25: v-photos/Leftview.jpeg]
V2 Izquierda
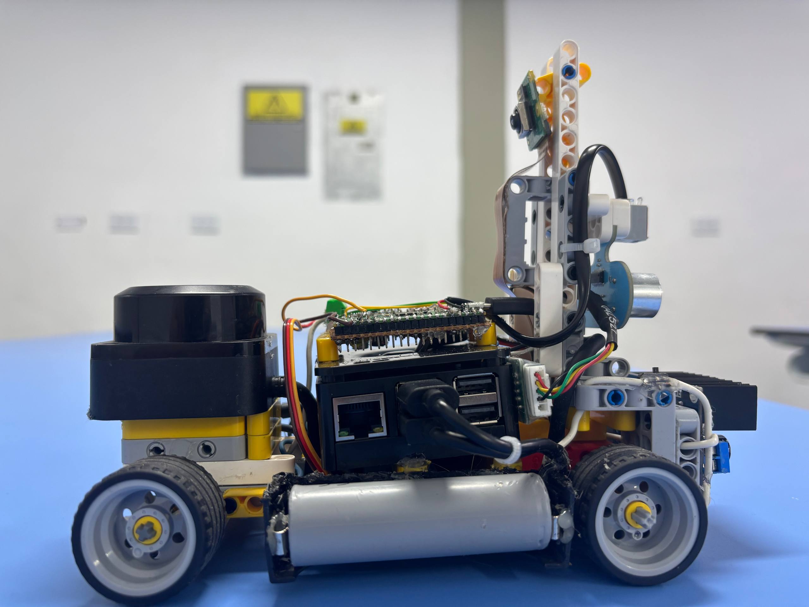
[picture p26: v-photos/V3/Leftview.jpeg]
V3 Izquierda
| **Lateral Izquierda** |  |  |  |
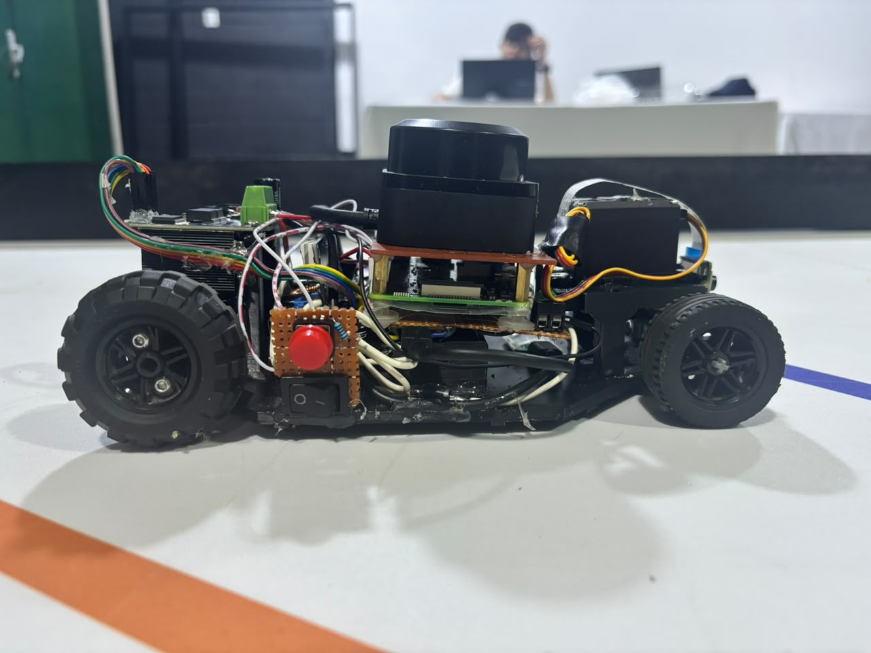
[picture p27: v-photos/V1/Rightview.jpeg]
V1 Derecha
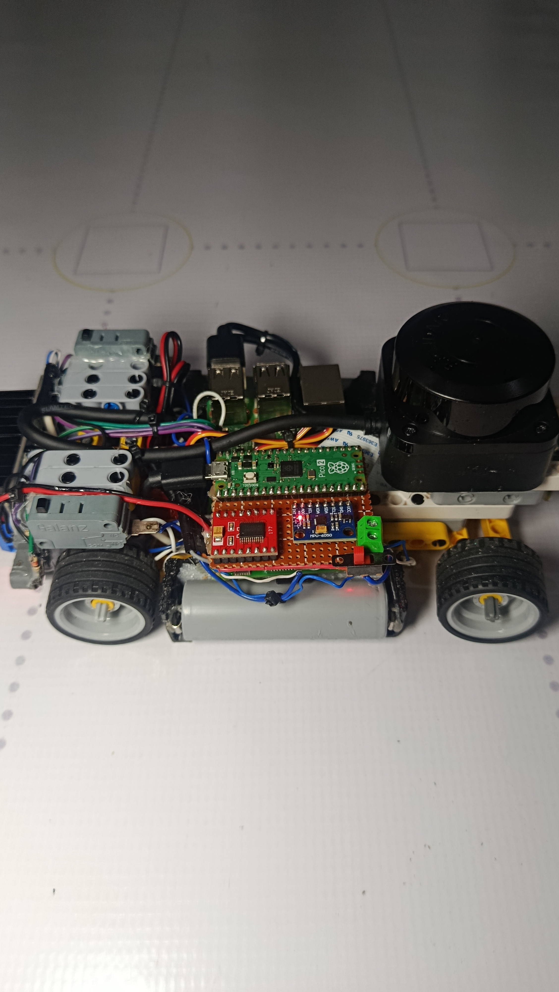
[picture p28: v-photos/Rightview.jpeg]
V2 Derecha
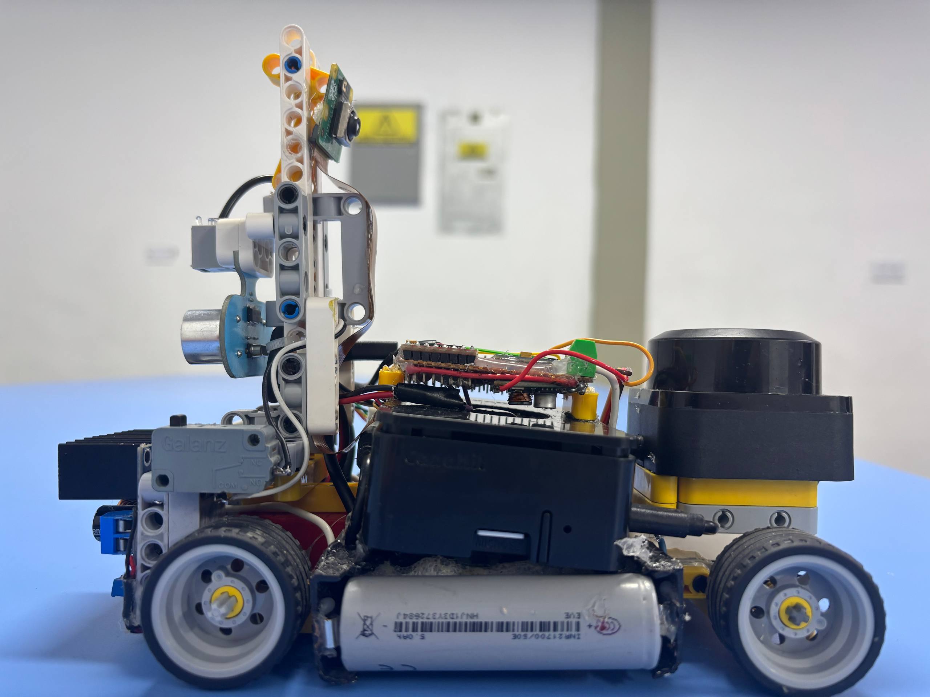
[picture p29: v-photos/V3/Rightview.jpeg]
V3 Derecha
| **Lateral Derecha** |  |  |  |

---
### 3.3 Galería de Inspección Técnica Obligatoria (Las 6 Capturas Reglamentarias)

Las capturas ortogonales del vehículo **tal como compite (V5)**, depositadas en `v-photos/V5/`. Las de los montajes anteriores se conservan en `v-photos/V4/`, `v-photos/V3/` y `v-photos/V1/` como evidencia de la evolución documentada en la sección 3.2.

| Vista | Captura | Descripción |
| :---: | :---: | :--- |
| **Frontal** (`V5/Frontview.jpg`) | Vista Frontal | El extremo que va primero. El **RPLiDAR C1 montado bajo, sobre el chasis**, con las dos ruedas directrices a los lados y el sensor de color asomando por debajo. Al fondo asoma la cámara en lo alto del mástil. |
| **Trasera** (`V5/Backview.jpg`) | Vista Trasera | El **mástil**, que lleva la cámara en lo alto y el **ultrasonido HC-SR04 mirando hacia atrás**, única medida real en ese sentido. Debajo, el regulador XL4016 con su display de tensión y el tren de tracción. |
| **Perfil Izquierdo** (`V5/Leftview.jpg`) | Perfil Izquierdo | El reparto completo de un vistazo: LiDAR bajo y delante, la Raspberry Pi 5 en el centro con la Pico 2 debajo, y el mástil atrás. La cámara mira hacia adelante **por encima** de todo, que es lo que impide que el LiDAR le tape el campo. |
| **Perfil Derecho** (`V5/Rightview.jpg`) | Perfil Derecho | El mismo perfil desde el otro lado, con el microinterruptor de corte de batería y las celdas 21700 sujetas bajo el chasis. |
| **Superior** (`V5/Topview.jpg`) | Vista Superior | Disposición central: el LiDAR adelantado al eje delantero y, detrás, la Raspberry Pi 5 en su carcasa con ventilador ocupando la planta superior. El cable plano naranja de la cámara sube al mástil. |
| **Planta del chasis** (`V5/Chasis_Pico_reubicada.jpg`) | Planta del chasis con la Pico 2 reubicada | El nivel que queda **bajo la Pi 5**: la Pico 2 en el piso del chasis, las dos celdas 21700 sujetas a los costados y el regulador de la línea lógica en el extremo. Es el cambio que define la V5. |
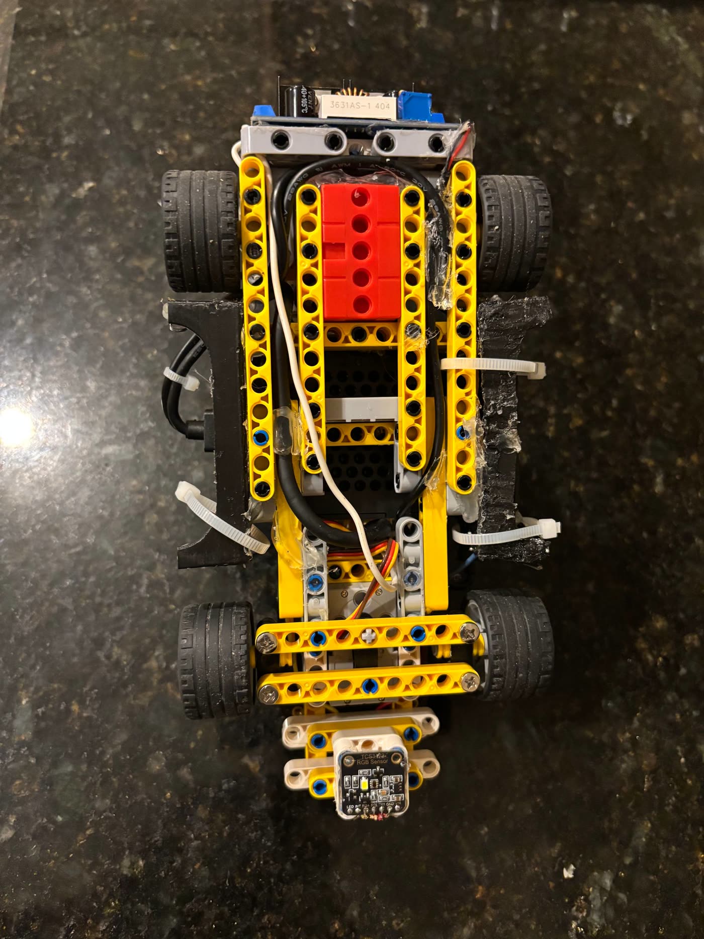
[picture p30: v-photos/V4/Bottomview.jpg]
Vista Inferior
| **Inferior** (`V4/Bottomview.jpg`) |  | **Tomada en la V4 y aún vigente:** el tren inferior no cambió en la V5. Estructura de vigas de fricción LEGO, el portapilas 21700 en rojo al centro, el servo de dirección, y el **TCS3472 sobre vigas Technic por delante del eje delantero**, fuera del contorno del chasis. |

### 3.4 Justificación de Ingeniería para la Selección de Componentes y Arquitectura de Sistemas (Trade-offs)

De acuerdo con las rigurosas restricciones de peso, inercia de rotación y estabilidad dinámica evaluadas en pista, el equipo aplicó los principios del pensamiento sistémico para balancear de forma óptima las variables físicas del prototipo. A diferencia de las arquitecturas convencionales de manufactura aditiva masiva (chasis impresos en 3D multicapa que elevan el peso por encima de los $1000\,\text{g}$), nuestro diseño optimiza la relación potencia-masa:

* **Ventaja Cinemática de la Reducción de Masa (V3: 720 g; V2: 613 g):**
  Al descartar un chasis totalmente impreso en 3D y migrar a una estructura de vigas de fricción LEGO, la V2 quedó en **613 g**. La versión que compite actualmente, **V3**, pesa **720 g**: añade 107 g por la Raspberry Pi 5 con carcasa, el mástil del LiDAR y el ultrasonido trasero (medición del 06-09-2026, sección 7.4). Aun con esa instrumentación, la masa sigue por debajo de los aproximadamente 800 g de V1. Como $F_c = \frac{m \cdot v^2}{r}$, reducir la masa disminuye linealmente la fuerza lateral requerida en curva; la mejora debe entenderse como una comparación V1→V3, no como si la V3 todavía pesara 613 g.

* **Fusión Sensorial Avanzada (LiDAR C1 vs. Ultrasonidos Tradicionales):**
  Se descartó el ultrasonido **como sensor de percepción principal** (tipo HC-SR04) por sus limitaciones físicas inherentes: retrasos por eco acústico, conos de dispersión muy amplios que generan falsos positivos y bucles de lectura bloqueantes. Para eso implementamos un escáner láser **RPLIDAR C1 (ToF)** por bus USB, que da una firma geométrica de 360° en tiempo real. Ahora bien, esa decisión tiene una excepción medida: el mástil del propio LiDAR le tapa el sector **140-213°**, así que hacia atrás no ve. En el parqueo el robot entra marcha atrás contra esa pared, y la "trasera" que el LiDAR reconstruye de los hombros en oblicuo llegó a discrepar **1777 mm contra 44** del ultrasonido en la misma pose (06-09). Por eso se añadió **un** HC-SR04 mirando atrás: no compite con el LiDAR, cubre exactamente el ángulo donde el LiDAR es ciego.

* **Procesamiento de Visión Nativo OpenCV contra Sensores Embebidos Cerrados:**
  Muchos equipos optan por cámaras inteligentes con procesadores integrados de firmware cerrado (como HuskyLens). Aunque simplifican la conexión, restringen severamente la flexibilidad algorítmica. Nuestra arquitectura utiliza la **Pi Camera Module 3** conectada por la interfaz CSI de alta velocidad directo al procesador de la **Raspberry Pi 5**. El procesamiento se realiza a nivel de software mediante código propio en **OpenCV**, permitiendo la manipulación directa de la matriz de píxeles en el dominio HSV, la aplicación de filtros morfológicos personalizados para eliminar el ruido lumínico de los boxes y la inyección dinámica de offsets angulares directo al servomotor Ackermann.

* **Por qué elegimos Baterías 21700 (2S) en lugar de LiPo clásicas o celdas 18650:**
  Las celdas de iones de litio 21700 proporcionan una densidad de corriente de descarga continua masiva de hasta $30\,\text{A}$. Al alimentar nuestro regulador de alta potencia **XL4016 (capacidad de hasta $8.0\,\text{A}$)**, garantizamos un blindaje eléctrico absoluto contra caídas de tensión (*brownouts*). Toda la etapa lógica (Raspberry Pi 5, Pico 2 y LiDAR) opera de manera holgada: el consumo real del sistema completo en marcha, medido con multímetro el 06-09, es de $1.39\,\text{A}$ (sección 4.4), previniendo reinicios críticos del sistema operativo cuando el motor demanda torque de arranque máximo al salir de las curvas.
---

### 3.5 Línea de Tiempo del Proyecto: qué se intentó, qué midió y qué cambió por eso

Las tablas anteriores comparan versiones de hardware. Esta cuenta **el orden en que se aprendieron las cosas**, porque el proyecto no avanzó de forma lineal y el punto de inflexión no fue un componente nuevo. Todo lo de abajo está respaldado por [`CHANGELOG.md`](CHANGELOG.md), que lleva el hash de commit de cada hito.

| Fase | Cuándo | Qué se resolvió | Qué obligó a cambiar |
| :--- | :---: | :--- | :--- |
| **Construir** | ene – jun 2026 | Estructura reglamentaria del repositorio, protocolo serie Pi↔Pico y máquina de estados base en la Pico 2. | La Pi 5 no estaba disponible para el equipo, así que la capa de alto nivel **bajó a una Pi 3B**. No fue una preferencia técnica: fue el hardware que había. |
| **Mecanizar** | jul 2026 | Chasis V2 en LEGO Technic ($613\,\text{g}$) y primera Ronda Cerrada funcional: calibración HSV propia, *tracker* del LiDAR y evasión con control proporcional. | El lado de evasión salía invertido y la cámara trabajaba en el espacio de color equivocado. Se arregló en pista, y de ahí sale el caso de estudio de la sección 8.2. |
| **Medir** | 27-07-2026 | **El punto de inflexión.** Se instrumentó telemetría por ciclo en CSV y un analizador que la resume. | Hasta aquí los parámetros de control se ajustaban por **observación cualitativa**. Desde aquí, con datos. Todo lo que este README afirma a partir de esta fecha tiene un CSV detrás. |
| **Chocar contra un límite** | 27 – 29-08-2026 | Asistencia de esquina, escape frontal y desempate de esquina simétrica con memoria persistente. | Se documentó el **límite de la reactividad pura**: un controlador que solo responde a lo que ve *ahora* no puede desempatar dos esquinas que se ven idénticas. Hizo falta memoria de estado, no más ganancia. |
| **Ampliar el cómputo** | 03 – 05-09-2026 | Vuelta a la **Raspberry Pi 5**. | La decisión se tomó con números, no por preferencia: el mismo procesado de imagen pasó de $67-72\,\text{ms}$ a $\mathbf{4.8\,\text{ms}}$ por cuadro, y la edad del barrido del LiDAR de $16.0\,\text{ms}$ de media a $\mathbf{0.1\,\text{ms}}$. Eso es lo que permitió subir la cámara a $1280\times720$. |
| **Cerrar la ronda** | 06 – 11-09-2026 | Ronda Abierta completa y grabada. Después, la secuencia entera de la Ronda de Obstáculos: salir del estacionamiento, tres vueltas y volver al cuadrante. | El conteo de vueltas dejó de hacerse por tiempo y pasó a contarse por **líneas de pista**, porque contar tramos devuelve el robot al mismo cuadrante del que salió sin importar dónde arrancara dentro de él. |

#### La decisión que más enseñó no fue técnica

El cambio de rumbo del proyecto ocurrió el **27 de julio**, y no fue un sensor ni un algoritmo: fue empezar a **grabar un CSV por ciclo** y a comparar corridas con un analizador en vez de con la memoria de quien miraba.

Lo que eso hizo posible se ve en la sección 9.3: cuatro hipótesis razonables que resultaron **falsas y se pudieron descartar con datos** en vez de seguir arrastrándolas. Frenar al ver un bloque sin color parecía prudente y empeoró el resultado (de 8 pilares sin fallo a 3 con 2 fallos). Encararlo para identificarlo parecía obvio y bajó el reconocimiento de color del $39.2\,\%$ al $26.8\,\%$. El consumo eléctrico parecía una restricción y resultó estar sobrado por un factor de $1.5\times$. La cámara parecía el problema de la fusión y era el denominador, lleno de bultos que no eran pilares.

Ninguna de esas cuatro conclusiones se podía alcanzar mirando al robot dar vueltas.

#### El ir y venir de la Raspberry Pi

Vale la pena registrarlo porque es el tipo de restricción que un equipo escolar encuentra de verdad: el proyecto **empezó** con una Raspberry Pi 5, **bajó** a una Pi 3B en junio por disponibilidad de hardware, y **volvió** a la Pi 5 en septiembre cuando se pudo. El código sobrevivió a las dos migraciones porque la frontera entre la capa que decide y la que ejecuta es un cable serie y dos líneas de texto: la Pico 2 nunca se enteró de qué computadora tenía enfrente.

Esa es la ventaja real de la arquitectura de dos cerebros, y no se eligió por eso — se descubrió al tener que cambiar de computadora dos veces.

---

## 4. Arquitectura Eléctrica y Distribución de Señales

Antes del detalle de cada etapa, esta es la vista completa de cómo viaja la información por el vehículo: qué sensor entra por dónde, qué decide cada una de las dos capas de cómputo y cómo llega la orden hasta las ruedas.

<p align="center">
  Diagrama de bloques de señales: sensores, Raspberry Pi 5, Pico 2 y actuadores
</p>

> **El diagrama se lee de arriba abajo y la división horizontal es la decisión de arquitectura más importante del proyecto.** Todo lo que exige juicio — reconocer un pilar, decidir por qué lado pasarlo, saber en qué vuelta va — ocurre en la Raspberry Pi 5. Todo lo que exige puntualidad — el ancho de cada pulso del servo, la integración del giroscopio — ocurre en la Pico 2. Entre las dos hay un único cable serie y un protocolo de dos líneas de texto, y esa estrechez es deliberada: obliga a que la frontera entre "decidir" y "ejecutar" sea explícita y auditable en el log de cualquier corrida.

### 4.1 Red de Distribución de Energía (Alimentación)

Para asegurar el correcto funcionamiento del vehículo autónomo y prevenir reinicios imprevistos (*brownouts*) en la Raspberry Pi debido a picos de consumo dinámico de los motores, se implementó un sistema de alimentación completamente desacoplado por etapas:

| Fuente / Regulador | Voltaje Entrada | Voltaje Salida | Corriente Máx. | Componentes Alimentados |
| --- | --- | --- | --- | --- |
| **Baterías 21700 (2S)** | $7.4\,\text{V} - 8.4\,\text{V}$ | Directo | $30\,\text{A}$ | Línea de alta potencia del Driver TB6612FNG (Motor DC). |
| **Regulador XL1509** | $7.4\,\text{V} - 8.4\,\text{V}$ | $6.0\,\text{V}$ | $2.0\,\text{A}$ | Servomotor de dirección (Etapa de potencia limpia). |
| **Regulador XL4016** | $7.4\,\text{V} - 8.4\,\text{V}$ | $5.1\,\text{V}$ | $8.0\,\text{A}$ | Raspberry Pi 5, Cámara Module 3 y RPLIDAR C1. |

>  **Nota eléctrica:** Todas las referencias de tierra (GND) del vehículo confluyen en una topología de estrella en un único punto común central. Esto unifica los umbrales lógicos y drena el ruido electromagnético generado por las conmutaciones de los motores.

#### Diagrama de Alimentación y Señales

Este es el diagrama **vigente**: describe el montaje que compite, con un solo botón de arranque y el consumo real medido incorporado.

<p align="center">
  Alimentacion y senales: bateria, tres etapas de regulacion, reparto Pi 5 / Pico 2 y mapa de pines
</p>

Debajo se conserva el **diagrama de cableado original** que el equipo usó durante el ensamblaje. Se mantiene porque documenta el proceso real, pero **ya no describe el vehículo actual**: la parte de la Pico 2 sigue vigente tal cual, mientras que en la Pi muestra los **dos** botones del selector de ronda, que hoy es **uno solo en `GPIO 21`** (sección 4.2). Ante cualquier discrepancia manda el diagrama de arriba.

<p align="center">
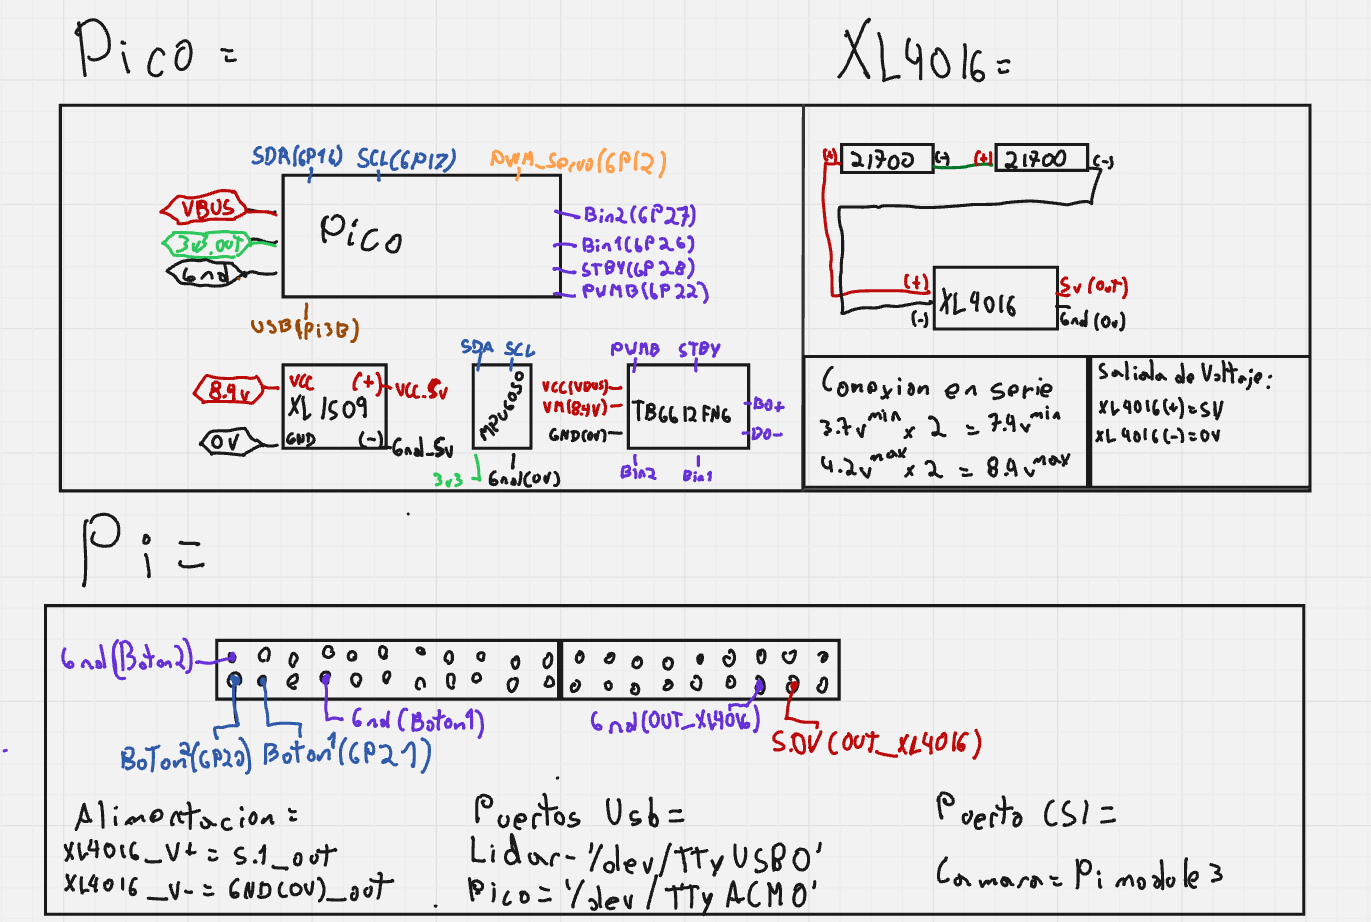
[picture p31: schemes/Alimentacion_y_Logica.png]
Diagrama de cableado original del ensamblaje: Pico 2, XL4016, XL1509 y GPIO de la Raspberry Pi
  
</p>

#### Implementación Física: Placa Perforada

La integración electrónica de la Pico 2, el driver TB6612FNG y el MPU6050 se soldó sobre una placa perforada (protoboard permanente) para eliminar el riesgo de falsos contactos por vibración que sí existía con conexiones de jumpers sueltos:

| Capa Superior — Pico 2 + MPU6050 | Capa Inferior — Soldadura y buses |
| :---: | :---: |
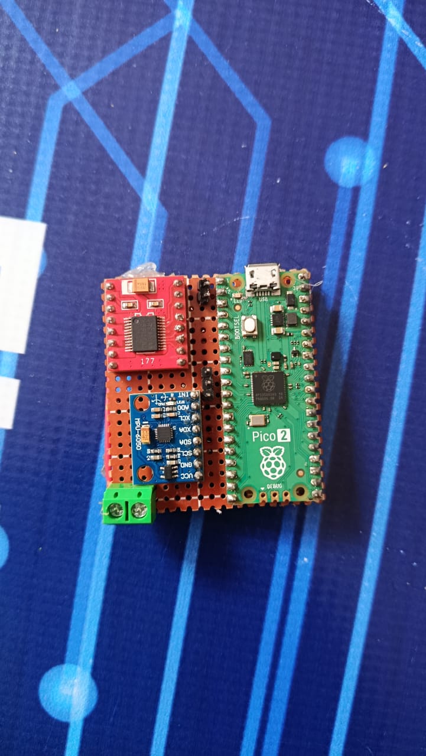
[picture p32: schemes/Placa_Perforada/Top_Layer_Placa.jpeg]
Capa superior de la placa perforada
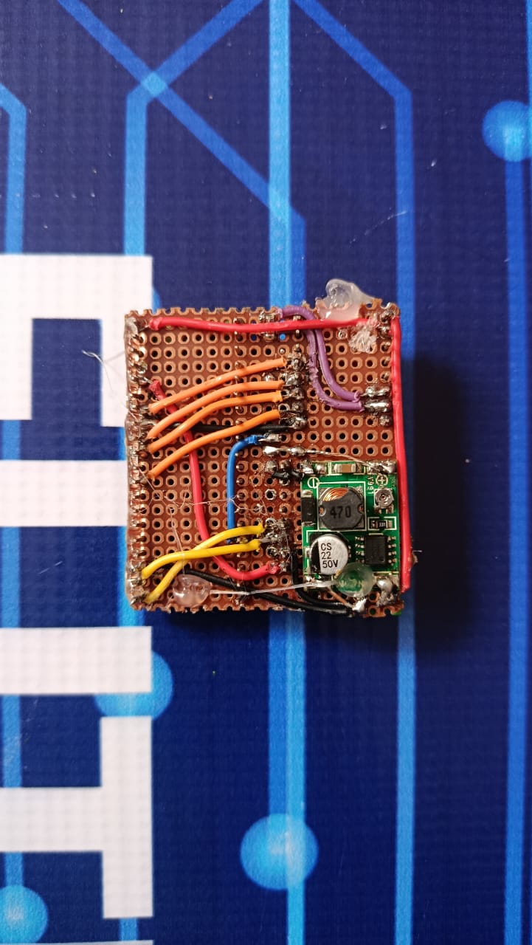
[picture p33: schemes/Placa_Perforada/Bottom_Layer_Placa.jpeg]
Capa inferior de la placa perforada
|  |  |

### 4.2 Catálogo de Componentes y Justificación de Selección

Cada sensor y actuador fue elegido, ubicado y calibrado con un criterio específico ligado a la geometría del campo de la WRO. La justificación comparativa completa (por qué se descartaron alternativas como ultrasonido o HuskyLens) está en la sección 3.4; aquí se documenta la selección final con evidencia fotográfica:

| Componente | Foto | Justificación de selección y ubicación |
| :--- | :---: | :--- |
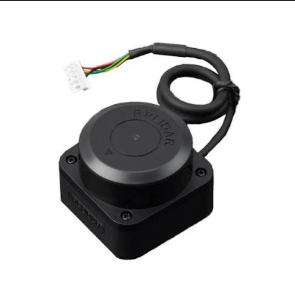
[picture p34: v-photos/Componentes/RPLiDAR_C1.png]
| **RPLiDAR C1** |  | Montado **bajo sobre el chasis**, con el mástil delantero reservado para la cámara. El haz corta a la misma altura tanto postes como paredes (ambos de 100 mm según el reglamento); la distinción entre uno y otro **no es por altura**, la hace la clasificación geométrica del cluster. El soporte tiene un coste conocido y medido: el LiDAR se ve a sí mismo, y por eso `lidar.blind_sectors_deg` enmascara el arco que ocupa. El plano de barrido sigue a **69 mm del piso**: al reubicar la cámara el LiDAR no cambió de altura. |
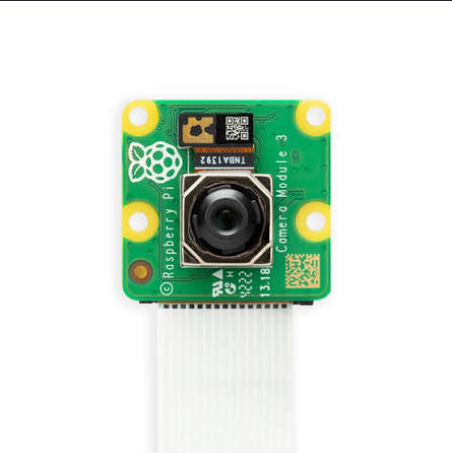
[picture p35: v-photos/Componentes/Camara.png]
| **Pi Camera Module 3** (estándar; HFOV efectivo **53,8° medidos**, no la Wide) |  | Montada en lo alto de un **mastil trasero**, desde donde mira hacia adelante por encima del vehiculo entero: asi el LiDAR, que va bajo y delante, no le tapa el campo. Estuvo al frente y por debajo del LiDAR hasta el remontaje final. **Es la Module 3 estándar, no la Wide**, aunque durante un tiempo se documentó al revés: `medir_fov.py` emparejó una esquina que el LiDAR sitúa en −21,5° con su borde en el frame y sale un HFOV efectivo de **53,8°**, que concuerda con los 51,9° previstos para la estándar recortada a 4:3 y no con los 85,6° de la Wide (ver [`optica.py`](src/pi5/ronda_curvas/optica.py)). Suponer el catálogo de la Wide inflaba el rumbo calculado de cada pilar 2,3 veces. |
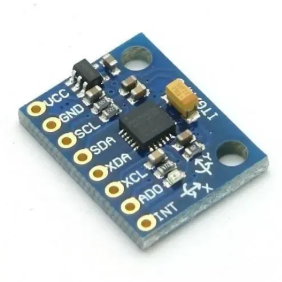
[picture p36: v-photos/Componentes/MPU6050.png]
| **MPU6050 (IMU)** |  | Montado rígidamente sobre la placa perforada, alineado con el eje longitudinal del chasis para que la lectura del eje Z corresponda exactamente al *yaw* del vehículo sin necesidad de compensar desalineación mecánica. |
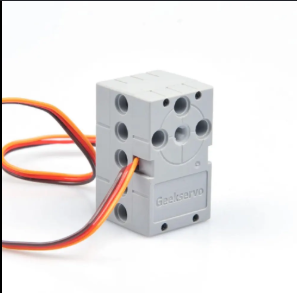
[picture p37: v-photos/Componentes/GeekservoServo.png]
| **Geekservo Servo (Dirección)** |  | Acoplado directo al `base_servo` del eje delantero; se eligió por compatibilidad mecánica nativa con las vigas Technic, evitando adaptadores impresos que añaden holgura al sistema de dirección. |
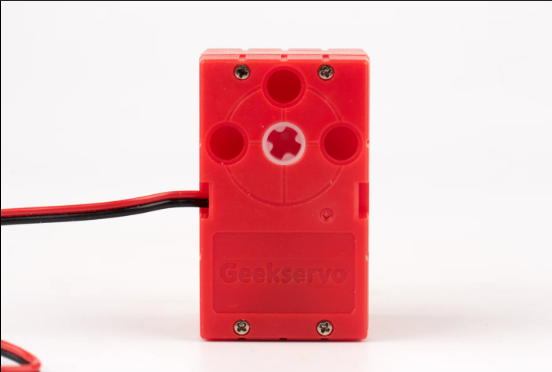
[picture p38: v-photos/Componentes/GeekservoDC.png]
| **Geekservo DC (Tracción)** |  | Seleccionado por su torque de bloqueo de $2.4\,\text{kg}\cdot\text{cm}$, validado matemáticamente en la sección 7.4 con un margen de seguridad de **2.18×** sobre los 720 g de la V3 (era 2.55× con los 613 g de la V2). |
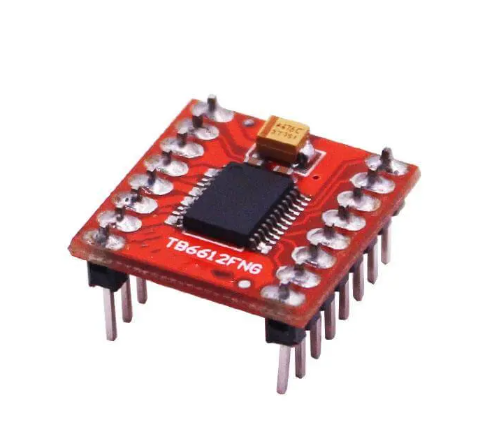
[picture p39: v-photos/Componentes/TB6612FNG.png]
| **Driver TB6612FNG** |  | Preferido sobre el clásico L298N por su topología MOSFET (menor caída de tensión y disipación térmica), crítico dado el presupuesto de corriente ajustado del sistema (sección 4.3). |
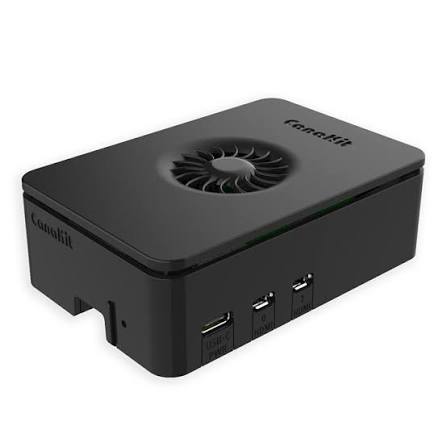
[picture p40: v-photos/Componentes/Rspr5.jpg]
| **Raspberry Pi 5** |  | Capa de alto nivel, montada en su carcasa Canakit con ventilador (es la que se ve en los perfiles de la sección 3.3). **Sustituye a la Pi 3B el 03-09-2026** (migración verificada: 3325 archivos y los 170 CSV idénticos por md5). El motivo es cómputo medido, no preferencia: el mismo pipeline de visión pasó de **67-72 ms a 4,8 ms** por cuadro a 640x360, y a 1280x720 —resolución que en la 3B no cabía— cuesta **22,2 ms**. La edad del barrido LiDAR bajó de 16,0 ms de media a **0,1 ms**. Eso es lo que permitió subir la cámara a 1280x720 @ 30 fps. |
| **Raspberry Pi AI HAT+ 26 TOPS** (Hailo-8) |  | Acelerador de inferencia montado sobre el conector de 40 pines de la Pi 5. **Sustituye solo el reconocimiento de pilares**, que era el punto débil medido de la visión: la máscara HSV depende de la luz del pabellón y obliga a recalibrar antes de cada jornada (sección 4.5). Las líneas de pista siguen leyéndose por HSV y por el TCS3472, y la geometría sigue saliendo del LiDAR: el acelerador no sustituye ninguna de esas dos vías, que son las que sostienen el conteo de vueltas y el centrado. Es lo que obligó a bajar la Pico 2 al piso del chasis, porque un HAT ocupa la planta inmediatamente superior a la placa. |
| **Raspberry Pi Pico 2** |  | Capa de bajo nivel de tiempo real: descarga a la Pi 5 de la generación de PWM y la integración del giroscopio, evitando que el *jitter* del sistema operativo Linux afecte la estabilidad del lazo de control físico. |
| **Reguladores XL1509 / XL4016** |   | Ver arquitectura de desacoplamiento por etapas en la sección 4.1 y análisis de margen de seguridad en la sección 4.3. |
| **Baterías 21700 (2S)** |  | Ver justificación de densidad de corriente en la sección 3.4. |
| **Botón físico de arranque (x1)** |  | **Un solo botón, en `GPIO 21` de la Pi 5** (entrada con *pull-up*, se dispara al ponerse a nivel bajo). Antes eran dos, uno por ronda. Se dejó en uno porque la ronda ya no se elige por hardware sino por el programa que se lanza (`ronda_nueva`, `ronda_abierta` o `ronda_cerrada`), y un único pulsador reduce el cableado y los modos de fallo en la línea de salida. El arranque sin botón existe solo como opción de banco (`--arranque-inmediato`) y la ronda oficial no la usa. |
| **Ultrasonido trasero HC-SR04** |  | Añadido para el parqueo, la única maniobra en que el robot va marcha atrás contra una pared que **el LiDAR no puede ver**: el soporte del propio sensor le tapa el sector 140-213°, así que la "pared trasera" que el LiDAR reporta se reconstruye de los hombros en oblicuo y no es una medida. Medido el 06-09 con el robot aparcado a mano: el ultrasonido leía 44 mm y el LiDAR 1777 mm con calidad 0,95. Va en la Pico 2 (`GP14` trigger / `GP15` echo) y está **34 mm por delante del punto más atrasado del robot**, así que la holgura real de la culata es su lectura menos esos 34. |
| **Sensor de Color TCS3472** |  | Montado **al frente del vehículo**, por delante del eje delantero y mirando el piso. Estuvo bajo el chasis; se adelantó para que la línea se lea antes de pisarla, lo que da margen de reacción en vez de avisar cuando ya se cruzó. Clasifica la línea del piso como `AZUL` o `NARANJA` y la Pico 2 la transmite en la trama de telemetría. Es la **única evidencia absoluta** del sentido de carrera: no depende del yaw ni de interpretar la geometría, porque las líneas están pintadas en la pista y su orden al cruzarlas no admite ambigüedad. Por eso puede *corregir* un sentido ya comprometido por geometría, cosa que ninguna otra fuente puede hacer (sección 5.3-C). Estuvo desconectado un tiempo tras la migración a la Pi 5 —la Pico respondía `COLOR:SIN_SENSOR`— y se volvió a conectar. |

#### Método de Calibración de Sensores

* **IMU (MPU6050):** Al energizar la Pico 2, `src/pico/main.py` promedia 100 lecturas del giroscopio en el eje Z (~1 segundo, con una espera de 10 ms entre muestras) para calcular `giro_z_offset` antes de entrar al bucle de control. Esto elimina el *bias* estático de fabricación del MEMS sin necesidad de recalibración manual entre carreras.
* **Cámara (Segmentación HSV):** `calibrar_hsv.py` transmite el feed de la Pi Camera por socket TCP a la laptop del equipo y expone sliders interactivos de OpenCV para ajustar en vivo los rangos `H/S/V` de verde y rojo (el rojo requiere dos rangos por el *wraparound* del matiz en 0°/180°). Los umbrales resultantes se copian al bloque `vision` de `src/pi5/ronda_nueva/configuracion.json` antes de cada jornada de pruebas, ya que la iluminación de los boxes varía respecto a la de la pista oficial.
* **Sensor de Color de Piso (TCS3472):** al arrancar, `src/pico/main.py` promedia 25 lecturas de saturación del piso blanco bajo la iluminación real (`calibrar_suelo_inicial()`) y fija `saturacion_base_pista` como ese promedio más un margen de 0.12 — un umbral dinámico en vez de un valor fijo que se desajusta con cada cambio de luz entre el box y la pista oficial. Cada lectura pasa además por un promedio móvil de 4 muestras en tono (H) y saturación (S) antes de clasificarse, para filtrar destellos puntuales del sensor.
* **Puntos de fallo considerados:** si la IMU se satura o pierde el bus I2C, `main.py` captura la excepción y fuerza `velocidad_z = 0.0` (el coche sigue guiándose solo por LiDAR en vez de trabar el bucle de control); si el LiDAR pierde la lectura de una pared, la Pi 5 congela el último ángulo válido (modo "Inercial", sección 5.3) en lugar de enviar un comando basado en datos corruptos.

### 4.3 Mapa de Conexiones Calibrado (Pinout)

#### Interfaces Digitales de la Raspberry Pi Pico 2

| Componente Físico | Pin Pico 2 | ID de Pin | Tipo de Señal | Función Técnico-Específica |
| --- | --- | --- | --- | --- |
| **Geekservo Dirección** | Pin 16 | `GP12` | Salida PWM | Inyección de pulso de posición ($50\,\text{Hz}$). |
| **TB6612FNG (STBY)** | Pin 34 | `GP28` | Salida Digital | Habilitación lógica del puente H ($1 = \text{Active}$). |
| **TB6612FNG (BIN1)** | Pin 32 | `GP27` | Salida Digital | Dirección de tracción (Línea de control lógica 1). |
| **TB6612FNG (BIN2)** | Pin 31 | `GP26` | Salida Digital | Dirección de tracción (Línea de control lógica 2). |
| **TB6612FNG (PWMB)** | Pin 29 | `GP22` | Salida PWM | Modulación de velocidad por ancho de pulso ($2\,\text{kHz}$). |
| **MPU6050 (SDA)** | Pin 21 | `GP16` | $\text{I}^2\text{C0}$ SDA | Línea de datos del bus inercial. |
| **MPU6050 (SCL)** | Pin 22 | `GP17` | $\text{I}^2\text{C0}$ SCL | Línea de reloj síncrono del bus inercial ($400\,\text{kHz}$). |
| **HC-SR04 (TRIG)** | Pin 19 | `GP14` | Salida Digital | Disparo del ultrasonido trasero, usado por el parqueo (sección 4.2). |
| **HC-SR04 (ECHO)** | Pin 20 | `GP15` | Entrada Digital | Retorno de eco. Es la única medida trasera real: el LiDAR tiene ciego el sector 140-213°. |
| **TCS3472 (SDA)** | Pin 24 | `GP18` | $\text{I}^2\text{C1}$ SDA | Línea de datos del sensor de color de piso. |
| **TCS3472 (SCL)** | Pin 25 | `GP19` | $\text{I}^2\text{C1}$ SCL | Línea de reloj del bus de color ($100\,\text{kHz}$, más lento que el de la IMU porque el TCS3472 no soporta $400\,\text{kHz}$ de forma confiable). |

#### Conexiones Maestras de la Raspberry Pi 5

* **Pi Camera Module 3:** Conectada a la interfaz nativa CSI mediante un cable flexible plano de 15 pines.
* **RPLIDAR C1:** Conectado directamente a un puerto USB 2.0 maestro (Comunicación UART integrada a $460\,800\,\text{bps}$).
* **Raspberry Pi Pico 2:** Enlazada por interfaz de datos USB corta operando bajo la clase de dispositivo COM Virtual (VCP) a una tasa fija de $115\,200\,\text{bps}$.
* **Botón de arranque:** un único pulsador contra masa en `GPIO 21`, leído con resistencia de *pull-up* interna. Es lo que da la salida en la ronda oficial.

### 4.4 Presupuesto de Consumo Energético y Gestión de Corriente

Para evitar caídas de tensión críticas (*brownouts*) cuando los actuadores demandan torque máximo, se calculó el presupuesto de corriente nominal y de pico (Stall) del sistema. **La tabla siguiente es la estimación por hoja de datos y se hizo con la Raspberry Pi 3B.** Debajo están las medidas reales del sistema con la Pi 5, tomadas con multímetro el 06-09-2026, que es lo que hay que mirar.

| Componente | Voltaje Operativo | Corriente Nominal | Corriente de Pico (Stall) | Regulador Asociado |
| :--- | :---: | :---: | :---: | :---: |
| **Raspberry Pi 3B** *(estimación original)* | $5.1\,\text{V}$ | $600\,\text{mA}$ | $1200\,\text{mA}$ | XL4016 (Línea lógica) |
| **RPLIDAR C1** | $5.0\,\text{V}$ | $250\,\text{mA}$ | $450\,\text{mA}$ | XL4016 (Línea lógica) |
| **Pi Camera Module 3**| $3.3\,\text{V} (CSI)$ | $280\,\text{mA}$ | $400\,\text{mA}$ | XL4016 / Interno Pi |
| **Geekservo Dirección**| $6.0\,\text{V}$ | $180\,\text{mA}$ | $800\,\text{mA}$ | XL1509 (Línea limpia) |
| **Motor DC (Tracción)**| $7.4\,\text{V} - 8.4\,\text{V}$ | $400\,\text{mA}$ | $2500\,\text{mA}$ | Directo (Batería 2S) |
| **Raspberry Pi Pico 2**| $5.0\,\text{V} (VBUS)$ | $40\,\text{mA}$ | $90\,\text{mA}$ | USB |

#### Consumo Real Medido (06-09-2026, banco del laboratorio)

La tabla anterior es **estimada por hoja de datos**. Estas son las medidas reales, tomadas con un multímetro ANENG M118A en serie con la batería y la fuente de banco a $8.4\,\text{V}$, que es lo que da un 2S de 21700 a plena carga. Se midieron tres estados, y el tercero (con la Pi apagada) es el que permite separar lo que consume el cerebro de lo que consume el resto:

| Estado | Corriente | Lectura de la foto | Evidencia | Qué incluye |
| :--- | :---: | :---: | :---: | :--- |
| **En funcionamiento** | $\mathbf{1.39\,\text{A}}$ | $1.499\,\text{A}$ |  | Todo: Pi 5, LiDAR girando, cámara, Pico 2, sensores, servo y motor de tracción en marcha. |
| **En reposo** | $\mathbf{0.61\,\text{A}}$ | $0.678\,\text{A}$ |  | Sistema energizado y ejecutándose, sin tracción. |
| **Con la Pi 5 apagada** | $\mathbf{0.21\,\text{A}}$ | $0.219\,\text{A}$ |  | Solo Pico 2, IMU, ultrasonido, servo y electrónica de potencia. |

> El multímetro oscila y la foto congela un instante, por eso se dan las dos cifras. Dos de las tres coinciden casi exactas (0,219 contra 0,21 y 0,611 contra 0,61, esta última en `En_reposo_mostrando_voltaje.jpeg`); la de funcionamiento difiere porque 1,499 A es un pico de arranque del motor y 1,39 A el valor sostenido, que es el que manda para el presupuesto. Los cálculos de abajo usan las cifras sostenidas. La foto `En_reposo_mostrando_voltaje.jpeg` documenta además la tensión de alimentación del banco durante la prueba.

**Lo que se deduce restando estados:**

$$I_{\text{Pi 5}} = 0.61 - 0.21 = \mathbf{0.40\,\text{A}} \qquad I_{\text{tracción}} = 1.39 - 0.61 = \mathbf{0.78\,\text{A}}$$

| Bloque | Corriente | % del total en marcha |
| :--- | :---: | :---: |
| Tracción y dirección en movimiento | $0.78\,\text{A}$ | $56\,\%$ |
| Raspberry Pi 5 (con cámara y LiDAR por USB) | $0.40\,\text{A}$ | $29\,\%$ |
| Pico 2, IMU, ultrasonido y electrónica de potencia | $0.21\,\text{A}$ | $15\,\%$ |

**Potencia y autonomía.** A $8.4\,\text{V}$ el consumo en marcha es $1.39 \times 8.4 = \mathbf{11.7\,\text{W}}$ ($10.3\,\text{W}$ con la batería ya a $7.4\,\text{V}$). Las celdas son INR21700/50E de $5.0\,\text{Ah}$, y **en 2S la capacidad no se suma**, solo la tensión:

$$t = \frac{5.0\,\text{Ah}}{1.39\,\text{A}} = 3.6\,\text{h} \quad\longrightarrow\quad \text{al } 80\,\% \text{ de descarga útil} = \mathbf{2.9\,\text{h}}$$

Una ronda de la WRO dura 3 minutos, así que la batería da para unas **58 rondas seguidas** sin recargar. La autonomía no es una restricción de este diseño: el límite práctico lo pone el desgaste mecánico, no la energía.

**Contraste con la estimación de hoja de datos.** El presupuesto de la tabla anterior predecía $2.14\,\text{A}$ de pico solo en la línea lógica. La medida real del sistema **completo** en marcha es $1.39\,\text{A}$, o sea que la estimación era conservadora por un factor de $1.5\times$ largo. Eso es lo esperable —las hojas de datos publican el peor caso— y confirma que el margen de los reguladores es mayor que el calculado, no menor. Sobre la corriente total de batería, el pico medido deja el XL4016 de $8.0\,\text{A}$ con un **margen del $82.6\,\%$**.

> **Cuidado al leer ese margen:** $1.39\,\text{A}$ es la corriente de **batería**, no la de cada regulador por separado. Repartir ese total entre el XL4016, el XL1509 y la línea directa del motor exigiría medir cada rama, y eso no se ha hecho. El margen por regulador de la sección siguiente sigue siendo la estimación de diseño.

#### Análisis de Margen de Seguridad en Reguladores:
1. **Regulador XL4016 (Línea de Control - Límites Lógicos):**
   * *Consumo máximo de pico estimado:* $1200 + 450 + 400 + 90 = 2140\,\text{mA}$ ($2.14\,\text{A}$).
   * *Capacidad del regulador:* Con una salida máxima por diseño de **$8.0\,\text{A}$**, el XL4016 opera de manera holgada con un **margen de seguridad del $73.25\%$** bajo las condiciones de estrés electrónico más extremas posibles en carrera.
2. **Regulador XL1509 (Línea de Potencia de Dirección):**
   * *Consumo máximo en bloqueo (Stall):* $800\,\text{mA}$ ($0.8\,\text{A}$).
   * *Capacidad del regulador:* Con una salida máxima de **$2.0\,\text{A}$**, el regulador opera con un **margen del $60\%$**, previniendo que el ruido inductivo del servo se filtre al bus de la CPU o afecte los sensores.

---

### 4.5 Geometría de Sensores: Alcance, Zonas Ciegas y Autoecos

La sección anterior dice **qué** sensores lleva el vehículo. Esta dice **desde dónde miran, hasta dónde llegan y qué no pueden ver**, porque un sensor mal ubicado no falla: miente, y miente de forma consistente, que es peor. Todos los números de abajo están medidos sobre el montaje que compite, no tomados de hoja de datos.

#### Posición medida de cada sensor

El origen es el eje de rotación del LiDAR. `x+` es a la derecha del vehículo, `y+` hacia adelante.

| Sensor | Posición respecto al LiDAR | Cubre | No puede ver |
| :--- | :--- | :--- | :--- |
| **RPLiDAR C1** | origen; plano de barrido a $69\,\text{mm}$ del piso | $360°$ nominales: paredes, esquinas y bultos de pilar | El arco $135°-199°$ (estructura propia) y la rueda delantera girada a tope |
| **Pi Camera Module 3** | mástil trasero, mirando adelante por encima del vehículo | Color de pilares y líneas del piso, $53.8°$ de HFOV **medidos** | Todo lo que quede fuera de ese cono; el color se pierde antes que el eco (ver abajo) |
| **HC-SR04 trasero** | $34\,\text{mm}$ por delante del punto más atrasado del chasis | El sector que el LiDAR tiene ciego por detrás | Cualquier cosa fuera de su cono; no da forma, solo distancia |
| **TCS3472** | al frente, por delante del eje delantero, mirando al piso | Las líneas naranja y azul de la pista | Nada que no esté justo debajo |
| **MPU6050** | rígido sobre la placa perforada, alineado con el eje longitudinal | Guiñada integrada | No es un sensor de entorno; deriva con el tiempo |

El chasis mide $242 \times 138\,\text{mm}$ y el LiDAR está **prácticamente centrado**: $68\,\text{mm}$ a cada costado, $54\,\text{mm}$ al morro y $188\,\text{mm}$ a la cola. Esa asimetría longitudinal —el LiDAR va muy adelantado— es lo que obliga a que la comprobación de holgura se haga **rumbo a rumbo contra la silueta real del chasis** y no contra un radio único: una lectura de $200\,\text{mm}$ deja $146\,\text{mm}$ de chapa libre mirando al frente y solo $12\,\text{mm}$ mirando atrás.

#### Zona ciega trasera del LiDAR, y por qué hay un ultrasonido

El conjunto mástil de cámara más soporte del ultrasonido tapa el LiDAR por detrás. **Remedido el 10-09-2026** con `diag_lidar_360.py` (25 barridos, robot quieto):

| Arco | Eco de la estructura propia | Tasa de aparición | Dispersión |
| :---: | :---: | :---: | :---: |
| $136° - 198°$ | $32-79\,\text{mm}$ | $25-100\,\%$ | $2-9\,\text{mm}$ |

Ese arco se enmascara en `lidar_mascara.py` con un grado de margen a cada lado ($135°-199°$), porque los bordes salen con tasa de eco **parcial**, que es el caso que peor se comporta: alterna entre $45\,\text{mm}$ y $8000\,\text{mm}$ en ciclos seguidos.

**Lo que costó no tenerlo bien medido** está en los CSV del 09-09 (tres corridas, 1634 ciclos): la distancia trasera valía $35-50\,\text{mm}$ en el $99.9\,\%$ de los ciclos, y los 447 episodios de marcha atrás duraron **todos exactamente un ciclo** — salían por emergencia trasera antes de retroceder nada. A $-35$ de PWM y $0.1\,\text{s}$ eso son $16\,\text{mm}$ por intento: el robot no podía desatascarse ni en principio. Por eso el HC-SR04 no es redundancia, es la **única** medida trasera fiable durante el estacionamiento.

#### El LiDAR se ve su propia rueda, y cómo se distingue de un muro

Con el volante al tope, la rueda delantera entra en el barrido. Esto bloqueó la maniobra de salida del estacionamiento durante dos corridas completas, y el modo de fallo era engañoso: el robot cortaba cada tramo del vaivén diciendo que tenía chapa a milímetros de un obstáculo que no existía.

**La medida que lo resuelve** es que un muro y una pieza propia no se comportan igual con el rumbo. Un muro plano a distancia perpendicular $D$ se lee $D/\sin(\text{rumbo})$: sube al alejarse de los $90°$. Una pieza a radio fijo del LiDAR se lee igual en todos los rumbos. Corrida del 11-09-2026 a las 13:23, tramo 23:

| Rumbo | Medido | Si fuera un muro |
| :---: | :---: | :---: |
| $36°$ | $64\,\text{mm}$ | $80\,\text{mm}$ |
| $38°$ | $61\,\text{mm}$ | $76\,\text{mm}$ |
| $40°$ | $61\,\text{mm}$ | $73\,\text{mm}$ |
| $42°$ | $64\,\text{mm}$ | $70\,\text{mm}$ |
| $44°$ | $64\,\text{mm}$ | $67\,\text{mm}$ |
| $46°$ | $65\,\text{mm}$ | $65\,\text{mm}$ |

Plano. Y el segundo indicio es que **el radio cambia entre corridas** ($61-66\,\text{mm}$ a las 13:23, $49-56\,\text{mm}$ a las 13:44) porque cambia el ángulo del volante, cosa que un muro no hace.

La corrección no enmascara un arco fijo —la rueda se mueve— sino que descarta por **distancia mínima creíble**: en los sectores donde asoma la rueda ($20°-110°$ y $250°-340°$), nada ajeno al vehículo puede estar a menos de $72\,\text{mm}$ sin que el chasis, de $68\,\text{mm}$ de semiancho, lo esté tocando ya. El muro exterior con el robot aparcado lee $80-81\,\text{mm}$: queda fuera y sigue contando. El sector frontal **no** entra en esa regla, porque ahí la silueta son $54\,\text{mm}$ y un obstáculo a $64$ sí es real.

#### La cámara llega menos lejos que el LiDAR, y eso manda sobre la estrategia

Dos medidas de óptica que cambiaron decisiones:

* **El HFOV es $53.8°$, no $85.6°$.** `medir_fov.py` emparejó una esquina que el LiDAR sitúa en $-21.5°$ con su borde en el frame. Durante un tiempo se documentó el módulo como la versión *Wide*; suponer ese catálogo **inflaba el rumbo calculado de cada pilar 2.3 veces**, que es un error de asociación, no de precisión: el pilar se emparejaba con el bulto equivocado del LiDAR.
* **Discrepancia cámara-LiDAR: $47\,\text{mm}$** sobre una tolerancia de $80$, con $194/194$ ciclos de fusión y $\pm 2\,\text{mm}$ de estabilidad (`diag_pilares.py`, pista montada).

Pero la limitación que manda es de **alcance**: el LiDAR ve el bulto de un pilar hasta unos $1400\,\text{mm}$ y la cámara solo le pone color desde unos $1100\,\text{mm}$ hacia dentro. Entre esas dos distancias el robot **sabe que hay algo y no sabe de qué lado pasarlo**, y pasar un pilar por el lado equivocado termina el recorrido.

Se probaron dos respuestas desde el control y las dos empeoraron el resultado, así que están descartadas con datos en la sección 9.3: frenar al ver un bulto sin color (el alcance bajó de $1128$ a $1056\,\text{mm}$ y la corrida pasó de 8 pilares sin fallo a 3 con 2 fallos) y encararlo para identificarlo (el color cayó del $39.2\,\%$ al $26.8\,\%$ y corrompió el estimador de sentido). `sonda_color.py` confirmó que la máscara HSV captura el $85\,\%$ del blob ideal a esa distancia: **el corte es geométrico, no de calibración**, y la salida es óptica —más resolución o más focal—, no de software.

#### Calibración de color en pista

Los umbrales HSV dependen de la luz del pabellón, que no es la del taller. Antes estaban fijos dentro de `vision.py`, de modo que recalibrar significaba editar Python por consola sin ver la máscara que se estaba cambiando.

Ahora `vision.py` lee `calibracion.json` si existe, y `calibrador_web.py` lo sirve en el navegador: cámara y máscara lado a lado, con el **área del blob en números**, que es el valor que de verdad decide si el robot ve el pilar o no. Si el archivo falta o está corrupto se usan los valores del código, así que el archivo solo puede mejorar la calibración, nunca dejar el vehículo sin una.

Se calibran cuatro colores, y los dos últimos importan tanto como los primeros: **naranja y azul son las líneas del piso, y de ellas sale el conteo de vueltas** (sección 5.3).

### 4.6 Integridad de Señal y Topología de Cableado

La sección 4.1 describe **cómo se reparte la energía** y la 4.3 **qué pin va a dónde**. Falta la capa intermedia: por qué el cableado está tendido como está. Ninguna de estas decisiones se tomó por orden ni por estética, y varias son consecuencia directa de una avería.

El vehículo tiene una fuente de ruido dominante y perfectamente identificada: el motor de tracción, conmutado por PWM a $2\,\text{kHz}$ desde el TB6612FNG, con un pico de arranque medido de $1.499\,\text{A}$ frente a los $1.39\,\text{A}$ sostenidos (sección 4.4). Todo lo que sigue existe para impedir que ese transitorio llegue a las líneas que deciden.

#### Las cuatro barreras, de la más fuerte a la más débil

| # | Barrera | Decisión de montaje | Modo de fallo que bloquea |
| :---: | :--- | :--- | :--- |
| 1 | **Separación de rieles** | Tres etapas independientes desde la misma batería: directo al motor, XL1509 para el servo, XL4016 para la lógica (sección 4.1) | El pico del motor hunde el riel de $5.1\,\text{V}$ y la Raspberry se reinicia a mitad de carrera |
| 2 | **Tierra en estrella** | Todas las masas confluyen en un punto único; ninguna se encadena de módulo a módulo | El retorno del motor comparte camino con el retorno lógico y desplaza el umbral de los flancos digitales |
| 3 | **Calibres diferenciados** | $18\,\text{AWG}$ en potencia, $22\,\text{AWG}$ en señal ([`BOM.md`](BOM.md), ítem 24) | Caída óhmica en la rama de tracción durante el pico de arranque |
| 4 | **Uniones soldadas** | Pico 2, TB6612FNG y MPU6050 soldados a placa perforada, sin *jumpers* (sección 4.1) | Falso contacto intermitente por vibración |

La cuarta merece detalle, porque se ganó con una avería y no con un cálculo. **Un *jumper* flojo no falla limpio: falla de forma intermitente y correlacionada con la vibración**, es decir, aparece en marcha y desaparece en el banco. Es el modo de fallo más caro de diagnosticar que existe en este vehículo, porque invita a buscar el error en el software. Soldar convirtió un fallo intermitente en una unión que o está o no está.

La segunda tiene una regla de montaje que parece menor y no lo es: **las masas no se encadenan**. Si el retorno del MPU6050 pasa por el punto de masa del driver antes de llegar al común, la corriente del motor —que en el pico es tres órdenes de magnitud mayor que la del bus I²C— genera una caída sobre ese tramo compartido que la IMU ve como un desplazamiento de su propia referencia de $0\,\text{V}$. El bus no se corrompe del todo: se degrada, que es peor.

#### Dos buses I²C separados, y a velocidades distintas

El pinout de la sección 4.3 asigna la IMU a `I2C0` ($400\,\text{kHz}$, `GP16`/`GP17`) y el sensor de color a `I2C1` ($100\,\text{kHz}$, `GP18`/`GP19`). Son **dos controladores físicamente distintos del RP2350**, no un bus compartido con dos direcciones, y esa es una decisión de aislamiento de fallos, no de rendimiento.

El motivo es una propiedad desagradable del I²C: **un esclavo que se cuelga manteniendo `SDA` a nivel bajo bloquea el bus entero**, no solo su propia transacción. Y el TCS3472 es, de los dos, el dispositivo con historial: no sostiene $400\,\text{kHz}$ de forma fiable —falla de manera intermitente a esa velocidad, por eso su bus va a $100$— y estuvo un tiempo respondiendo `COLOR:SIN_SENSOR` tras la migración a la Pi 5.

Si ambos compartieran bus, un cuelgue del sensor de color se llevaría por delante la lectura de la IMU. **Y la IMU es la que sostiene el rumbo y cuenta las vueltas**: perderla no degrada una función accesoria, termina la corrida. Separarlos cuesta dos pines y elimina esa dependencia por completo.

> Compartir bus habría tenido además un coste permanente: el I²C corre a la velocidad de su participante más lento, así que el bus entero habría bajado a $100\,\text{kHz}$ para acomodar al TCS3472, degradando cuatro veces la tasa de la IMU sin ninguna necesidad, teniendo el RP2350 dos controladores disponibles.

#### El enlace entre las dos placas

La frontera entre la Pi 5 y la Pico 2 es el único punto donde una interferencia podría corromper una orden de control sin que nada lo note. Está protegida por construcción y no por blindaje:

* **Es USB, no UART sobre cables sueltos.** Señalización diferencial sobre par trenzado: el ruido que acopla lo hace por igual en ambos conductores y se cancela en el receptor. El cable es además deliberadamente **corto** ([`BOM.md`](BOM.md), ítem 22).
* **El protocolo es texto de dos líneas.** Una trama corrompida no se interpreta como una orden distinta y plausible: no parsea, y se descarta. La estrechez del protocolo, elegida por auditabilidad (sección 4), resulta ser también la defensa contra la corrupción silenciosa.

#### Lo que no está medido

No hay captura de osciloscopio del riel de $5.1\,\text{V}$ durante el transitorio de arranque del motor. Las cuatro barreras de arriba son decisiones de diseño justificadas y el sistema no ha vuelto a reiniciarse en pista desde que están las tres etapas separadas, pero **la ausencia de reinicios es evidencia de que el margen basta, no una medida de cuánto margen hay**. Cerrar ese hueco requiere un osciloscopio, que es el único instrumento del que el equipo no dispone.

Tampoco hay un código de colores documentado para el cableado. Los calibres sí están normalizados ($18/22\,\text{AWG}$), pero la asignación de color por función es la del taller y no se ha llevado al papel, de modo que hoy no es reproducible por un tercero a partir de este documento.

---

## 5. Capa de Percepción y Alto Nivel (Raspberry Pi 5)

La Raspberry Pi 5 se encarga de los procesos que demandan alta capacidad de cómputo. Sustituyó a la Pi 3B el 03-09-2026 (sección 4.2); los números de tiempo de este README que vengan de la 3B están marcados como tales. Mediante programación concurrentemente multihilos (`threading`), decodifica los datos en crudo del LiDAR y las imágenes de la cámara, calculando las decisiones estratégicas de navegación.

### Diagrama de Arquitectura de Software

El siguiente diagrama ilustra la orquestación actual de `prueba_abierta.py`, desde el botón de salida hasta el control de bajo nivel. El antiguo servicio de inicio se conserva únicamente como referencia:

```mermaid
graph TD
    A["Lanzamiento manual en Pi 5\nprueba_abierta.py"] --> B["Espera botón único\nGPIO 21"]
    B -->|"Pulsado"| C["Arma el programa\ny arranca hilo LiDAR"]

    C --> D["LiDAR C1: barrido de 360°\nventanas laterales"]
    D --> E["Centrado proporcional\nerror = izquierda - derecha"]
    E -->|"UART: velocidad, ángulo"| F["Raspberry Pi Pico 2"]
    F --> G["Saturación de consigna\ny PWM de motor/servo"]
    F -->|"UART: IMU:<yaw>"| H["Hilo de telemetría\nen prueba_abierta.py"]
    H --> I["Integra yaw y decide\nlas fases de vuelta/parqueo"]
    I --> E

    J["systemd / controlador_inicio.py\nreferencia histórica, deshabilitado"] -. "no participa en la ronda actual" .-> A

```

> **Alcance del diagrama:** representa el flujo que implementa
> `src/pi5/ronda_abierta/prueba_abierta.py`: un único botón en GPIO 21, LiDAR
> para el centrado y telemetría IMU para el conteo angular. `systemd`,
> `controlador_inicio.py` y el protocolo `WD:OK/WD:STOP` pertenecen al
> orquestador/firmware más reciente de `ronda_nueva`; no son estados ni
> requisitos de arranque de este script de prueba.

### 5.1 Orquestación del Sistema y Demonio de Arranque Autónomo

Para garantizar que el vehículo sea 100% autónomo desde el momento en que se conecta la batería (requisito estricto de la WRO), la Raspberry Pi 5 lanza la ronda completa al arrancar el sistema operativo mediante una unidad `systemd`.

#### Configuración del Servicio del Sistema (`systemd`)

La unidad se instala en `/etc/systemd/system/wro.service` y el archivo real, listo para copiar durante la reproducción del sistema, está en [`src/pi5/wro.service`](src/pi5/wro.service):

```ini
[Unit]
Description=Ronda WRO (abierta u obstaculos) - Team Los Cedros
After=multi-user.target
Conflicts=shutdown.target

[Service]
Type=oneshot
User=pi
WorkingDirectory=/home/pi/ronda_curvas
Environment=PYTHONUNBUFFERED=1
ExecStartPre=/bin/sleep 10
ExecStart=/bin/bash -lc 'cd /home/pi/ronda_unificada_20260916 && exec python3 -u ronda_unificada.py'
RemainAfterExit=yes
TimeoutStartSec=0
StandardOutput=append:/home/pi/ronda_curvas/logs/servicio.log
StandardError=append:/home/pi/ronda_curvas/logs/servicio.log

[Install]
WantedBy=multi-user.target
```

El servicio no arranca el motor: lanza `ronda_unificada.py`, que **espera el pulsador de `GP21`** antes de mover nada. La señal de que está cargado y listo es la línea `[LISTO] RONDA UNIFICADA...` en el log; al pulsar, arranca. Esto cumple las dos condiciones a la vez — el sistema es autónomo desde que se conecta la batería, y la salida la da una acción física sobre el robot, como exige el reglamento.

#### El servicio hace exactamente lo que se haría a mano

Durante la competencia del 17-09 el despachador se retiró. La unidad ya no lee ningún archivo de selección: ejecuta **literalmente el comando que el equipo escribiría en la terminal**, y nada más.

```ini
WorkingDirectory=/home/pi/ronda_unificada_20260916
ExecStart=/bin/bash -lc 'cd /home/pi/ronda_unificada_20260916 && exec python3 -u ronda_unificada.py'
```

> **Por qué se simplificó en pleno evento.** El despachador (los scripts `correr_ronda`, `ronda_activa` y `ronda`) resolvía un problema real —elegir ronda sin laptop delante— pero añadía tres piezas que podían fallar entre la orden y el motor. En competencia, cada capa intermedia es una hipótesis más que descartar cuando algo no arranca. La ronda de obstáculos es la que se corre, así que la unidad la lanza directa. La Ronda Abierta se lanza a mano con `python3 -u prueba_abierta.py`, que es lo que se hacía igualmente.

El `-l` da al proceso el mismo entorno de login que tendría por SSH, y el `exec` hace que `python3` sea el proceso principal de la unidad, para que `systemctl stop` lo pare directo sin dejar un `bash` huérfano en medio.

> **El LED no es la señal de listo en esta ronda.** `ronda_unificada.py` no enciende el LED de la Pico — eso lo hacía `esperar_boton.py`, del paquete anterior. La señal buena es la línea `[LISTO] RONDA UNIFICADA...` en `~/logs/servicio.log`. Un LED apagado aquí no indica fallo.

Cuatro decisiones de esta unidad no son cosméticas:

* **`After=multi-user.target` y `ExecStartPre=/bin/sleep 10`.** El enlace con la Pico se abre en el primer segundo del script; sin margen para que el USB enumere `/dev/ttyACM0`, el servicio arranca antes que el hardware y muere.
* **Sin `Restart=`.** La unidad anterior tenía `Restart=always`, que relanzaba la ronda entera en cuanto terminaba: el robot volvía a salir del estacionamiento solo, una y otra vez. Una carrera se lanza una sola vez.
* **`TimeoutStartSec=0`.** El servicio se pasa la mayor parte del tiempo esperando el pulsador, y el límite de 90 s que `systemd` aplica por defecto a los `oneshot` lo mataría antes de que nadie lo pulsara.
* **Registro a archivo además del diario.** `logs/servicio.log` sobrevive al reinicio y no depende de `journalctl`, que en una tarjeta SD con escritura volátil puede quedarse corto.

> **Para lanzar a mano por SSH hay que parar el servicio antes** (`sudo systemctl stop wro.service`). Si no, los dos procesos se disputan el GPIO del pulsador y el lanzamiento manual aborta con `GPIO ocupado`.

### 5.2 Estructura Modular del Script de Carrera (Fragmentos Clave)

`src/pi5/ronda_abierta/prueba_abierta.py` usa una máquina de estados propia y no usa el sensor de color ni cuenta líneas de pista. El hilo de telemetría recibe `IMU:<yaw>` desde la Pico, integra los cambios normalizados a $[-180°, 180°]$ y emplea el valor absoluto acumulado para contar tres vueltas: 990° inicia la aproximación y 1080° marca las tres vueltas completas. El LiDAR captura una firma lateral al inicio y mantiene el centrado proporcional durante las tres fases móviles.

```mermaid
stateDiagram-v2
    [*] --> ESPERANDO_BOTON
    ESPERANDO_BOTON --> CALIBRANDO: Botón GPIO21 presionado (fase_actual = "CALIBRANDO")
    CALIBRANDO --> CAPTURA_INICIAL: Hilo LiDAR detecta fase "CALIBRANDO" y activa el barrido
    CAPTURA_INICIAL --> CARRERA: Primer barrido completo -- guarda la firma de pared inicial (Izq/Der en mm)
    CARRERA --> BUSCANDO_PARQUEO: yaw acumulado absoluto >= 990° (1080° - 90°)
    BUSCANDO_PARQUEO --> AVANZANDO_AL_PARQUEO: yaw acumulado absoluto >= 1080° (3 x 360°)
    AVANZANDO_AL_PARQUEO --> PARANDO: tiempo >= TIEMPO_AVANCE_70CM O firma lateral coincide tras 1 s
    PARANDO --> [*]: apagar_sistema() -- manda 0,0, cierra serial/GPIO y sale

    note right of CARRERA
        La IMU se integra entre muestras,
        corrigiendo los saltos 359° -> 0°.
        No hay conteo de color ni detección
        de líneas en este script.

        Estado del valor actual:
        TIEMPO_AVANCE_70CM = 0.0 s.
        Por tanto la primera condición de
        parada se cumple en el siguiente
        barrido; debe calibrarse antes de
        usar el parqueo en pista.
    end note
```

A continuación se muestran los fragmentos que gobiernan las transiciones reales:

```python
def hilo_comunicacion_pico():
    """Hilo asincrono: telemetria IMU y conteo angular de vueltas."""
    global ser_pico, angulo_acumulado_robot, fase_actual
    global angulo_imu_previo, tiempo_inicio_avance
    # ... [Inicializacion serial a 115200 bps] ...
    while corriendo:
        if ser_pico.in_waiting > 0:
            try:
                linea = ser_pico.readline().decode('utf-8').strip()
                if "IMU:" not in linea:
                    continue
                campos = {}
                for parte in linea.split(','):
                    if ':' in parte:
                        clave, valor = parte.split(':', 1)
                        campos[clave.strip().upper()] = valor.strip()
                if "IMU" not in campos:
                    continue
                valor_crudo_imu = float(campos["IMU"])
                if fase_actual in ["ESPERANDO_BOTON", "CALIBRANDO"] or angulo_imu_previo is None:
                    angulo_imu_previo = valor_crudo_imu
                    angulo_acumulado_robot = 0.0
                    continue
                delta_angulo = valor_crudo_imu - angulo_imu_previo
                if delta_angulo > 180.0:
                    delta_angulo -= 360.0
                elif delta_angulo < -180.0:
                    delta_angulo += 360.0
                angulo_acumulado_robot += delta_angulo
                angulo_imu_previo = valor_crudo_imu
                progreso_angular = abs(angulo_acumulado_robot)
                if fase_actual == "CARRERA" and progreso_angular >= 990.0:
                    fase_actual = "BUSCANDO_PARQUEO"
                elif fase_actual == "BUSCANDO_PARQUEO" and progreso_angular >= 1080.0:
                    fase_actual = "AVANZANDO_AL_PARQUEO"
                    tiempo_inicio_avance = time.time()
            except: pass
        time.sleep(0.005)

def procesar_ciclo_completo_lidar():
    """Guiado proporcional por fase y parada final."""
    global dist_derecha_min, dist_izquierda_min, fase_actual, tiempo_inicio_avance

    error_lateral = dist_izquierda_min - dist_derecha_min
    angulo_objetivo = error_lateral * KP_LATERAL

    if fase_actual == "CARRERA":
        enviar_comando_navegacion(VELOCIDAD_CRUCERO)
    elif fase_actual == "BUSCANDO_PARQUEO":
        enviar_comando_navegacion(VELOCIDAD_PARQUEO)
    elif fase_actual == "AVANZANDO_AL_PARQUEO":
        enviar_comando_navegacion(VELOCIDAD_PARQUEO)
        tiempo_transcurrido = time.time() - tiempo_inicio_avance
        coincidencia_geometrica = (tiempo_transcurrido >= TIEMPO_MINIMO_PARA_FIRMA
                                    and abs(dist_izquierda_min - initial_izquierda) < 80.0
                                    and abs(dist_derecha_min - initial_derecha) < 80.0)
        if tiempo_transcurrido >= TIEMPO_AVANCE_70CM or coincidencia_geometrica:
            fase_actual = "PARANDO"
            for _ in range(8): ser_pico.write(b"0,0\n")
            apagar_sistema(None, None)

```

> **Nota de estado:** `prueba_abierta.py` no instancia `comun/registro_metricas.py`, así que no deja un CSV por corrida. Además, `TIEMPO_AVANCE_70CM` vale actualmente `0.0`; el diagrama no lo interpreta como un parqueo de 70 cm ya validado, sino como una parada inmediata pendiente de calibración.

### 5.3 Estrategia de Navegación Justificada por Rondas (Geometría del Campo)

Nuestra arquitectura de software aborda las dos disciplinas del torneo de forma segregada, adaptándose rigurosamente a las condiciones geométricas del circuito:

#### A. Ronda Abierta (Navegación Reactiva Simétrica)

La meta en la Ronda Abierta es mantener la velocidad lineal máxima constante reduciendo el desplazamiento angular innecesario.

* **Lógica del Algoritmo:** El RPLIDAR C1 barre en ventanas angulares simétricas a cada lado del vehículo. Al calcular el error de descentrado entre las distancias mínimas detectadas contra las paredes laterales:

$$e(t) = \text{dist}_{\text{izquierda}} - \text{dist}_{\text{derecha}}$$

el script aplica una ganancia proporcional (`KP_LATERAL`) para enviar micro-correcciones de dirección a la Pico 2.
* **Manejo de Casos Extremos (Puntos de Fallo) — Modo "Inercial":** Si el vehículo entra muy sesgado en una curva y el LiDAR pierde temporalmente la lectura de una de las paredes (lectura > 4000mm), el script **sostiene el último valor válido conocido de esa pared** en vez de sustituirlo por un valor fijo arbitrario. Esto se corrigió durante la depuración de la Ronda Cerrada (sección 8.2): la implementación original saltaba a un valor fijo de 2000mm apenas se perdía la lectura, lo que podía producir un giro brusco justo al entrar en una curva cerrada. La versión actual de ambos scripts (`ronda_abierta.py` y `ronda_cerrada.py`) sostiene el dato real más reciente. *Nota de alcance:* todavía no se integra el giroscopio de la Pico para predecir la posición de la pared durante la pérdida de señal — es una mejora identificada, no implementada aún.

#### B. Ronda Cerrada (Fusión Sensorial Visión Artificial + LiDAR)

En la Ronda Cerrada, la presencia de pilares de obstáculos (bloques rojos y verdes) rompe la simetría de las paredes del circuito, requiriendo una estrategia asimétrica:

* **Detección por Visión (Capa OpenCV):** La cámara Pi Module 3 captura el frente de la pista. El hilo de cámara en `src/pi3B/ronda_cerrada/vision.py` (portado a `src/pi5/ronda_cerrada/` y superado por `ronda_nueva/vision_pista.py`) (ver sección 8.2 para el historial de depuración) transforma la matriz de imágenes al espacio de color HSV (Hue-Saturation-Value) para aislar los bloques mediante máscaras de umbralización calibradas con `calibrar_hsv.py`. Se extraen los contornos y se calcula el centroide del objeto más grande.
* **Lógica de Esquiva y Evasión:** Cuando un obstáculo es detectado, se activa la lógica de evasión según las reglas del torneo:
1. Si el bloque es **Verde**, el carro debe evadir por el carril **izquierdo**. El software inyecta un offset angular negativo a la dirección.
2. Si el bloque es **Rojo**, el carro debe evadir por el carril **derecho**. El software inyecta un offset angular positivo.

* **Validación de Cercanía con LiDAR:** Para evitar giros falsos causados por reflejos distantes, la decisión de esquivar se valida cruzando los datos de color con un *tracker* de posición basado en clustering del LiDAR (ver sección 4.2). La maniobra se ejecuta solo cuando el LiDAR confirma proximidad real, y el algoritmo proporcional vuelve a estabilizar el coche por las paredes libres una vez que el tracker confirma que el obstáculo quedó atrás.

#### Máquina de Estados de Evasión (`navegacion.py`)

Máquina de estados vigente tras la reescritura modular de la navegación de la Ronda Cerrada. La evasión dejó de usar ángulos fijos por estado: el giro de `APROXIMACION` se calcula por **pure pursuit geométrico** hacia un punto de paso lateral al poste (posición real medida por el tracker LiDAR), y la superación del poste se decide por **odometría** (rotación IMU + traslación por velocidad comandada), no por cronómetro:

```mermaid
stateDiagram-v2
    [*] --> CRUCERO

    CRUCERO --> APROXIMACION: tracker confirmado (2+ barridos) con poste a menos de 900mm, O frontal bajo 700mm con color de camara
    APROXIMACION --> SOBREPASO: poste a la altura del morro (y bajo 180mm) O al costado O superado, O timeout 5.9s
    SOBREPASO --> REINCORPORACION: odometria confirma poste detras de la cola (y bajo -280mm), O timeout 1.6s
    REINCORPORACION --> CRUCERO: error de centrado (izq-der) menor a 120mm, O timeout 2.5s

    CRUCERO --> RETROCESO: EMERGENCIA -- frontal bajo 120mm O lateral bajo 80mm (chequeo global, cualquier estado)
    APROXIMACION --> RETROCESO: EMERGENCIA
    SOBREPASO --> RETROCESO: EMERGENCIA
    REINCORPORACION --> RETROCESO: EMERGENCIA
    RETROCESO --> CRUCERO: choque trasero bajo 250mm, O despejado (frontal>300 e izq/der>160) tras 0.6s minimo, O timeout 3.5s

    note right of APROXIMACION
        Pure pursuit hacia el punto de paso, unos 260mm
        al lado del poste, segun regla WRO (ROJO derecha,
        VERDE izquierda). Angulo proporcional al bearing
        hacia ese punto, recortado al recorrido real y
        asimetrico del servo (+25 izq / -20 der). Se
        mezcla con el centrado de pared si la pared del
        lado del giro se acerca (misma logica en SOBREPASO
        y REINCORPORACION, corrigio un bug real donde la
        evasion no veia las paredes y se les clavaba).
        El timeout se deriva de la velocidad medida en
        pista, no es un numero suelto: si se cambia la
        traccion hay que remedir (ver 8.3).
    end note

    note right of SOBREPASO
        Mantiene el RUMBO DE ENTRADA a este estado (P
        sobre ese heading), no el rumbo previo a la
        evasion -- ese era un bug real que deshacia la
        esquiva justo al lado del poste (ver 8.3). El
        timeout tambien esta acotado por la pared, no
        solo por el poste: mas tiempo aqui es excursion
        lateral acumulada con el servo casi recto.
    end note

    note right of REINCORPORACION
        Vuelve al centro por POSICION (mismo control que
        CRUCERO), no por rumbo: un lazo de rumbo puede
        cumplir el objetivo entero y dejar el robot
        pegado a un muro porque enderezar estando
        desplazado no corrige el desplazamiento (ver 8.3).
    end note

    note right of RETROCESO
        Control P en vivo sobre el perfil LiDAR de 360
        grados. Gira hacia la diagonal trasera con mas
        espacio en cada ciclo, no un signo fijo. Sale en
        cuanto el peligro se despeja en vez de agotar
        siempre el timeout -- version anterior reorientaba
        el robot 50-60 grados de mas por episodio (ver 8.3).
    end note
```

> El bloque `RETROCESO` es un chequeo de seguridad que se evalúa en **cada ciclo, sin importar el estado actual** (excepto si ya está en él), por eso el diagrama lo muestra como alcanzable desde los cuatro estados normales de la maniobra. La lógica completa vive en `src/pi3B/ronda_cerrada/navegacion.py` -- portada sin cambios a `src/pi5/ronda_cerrada/` -- como clase pura sin I/O (probada con barridos sintéticos fuera del robot); `ronda_cerrada.py` quedó como orquestador delgado con *watchdog* de percepción. El LiDAR (`src/pi3B/comun/lidar_geometria.py`) construye un perfil de distancia mínima en los 360° completos (1 grado por bin) en cada barrido; los sectores fijos (pared, frontal, diagonales traseras) son consultas sobre ese perfil, no cálculos independientes.
>
> Los timeouts de `APROXIMACION` y `SOBREPASO` no son constantes sueltas: `navegacion.py` los calcula a partir de `tracker.MM_POR_SEG_A_PWM100` (400mm/s, medido en pista — sección 8.3) y la velocidad de PWM de cada fase, con un margen de 1.3× sobre el tiempo teórico. Son **red de seguridad**, no la vía normal — la transición esperada es geométrica (por posición del tracker), y si el timeout es más corto que la física, se convierte en la ruta principal sin que nadie lo note (exactamente lo que pasaba antes de medir la velocidad real).

#### C. Sentido de Carrera — Tres Evidencias, y una que puede Corregir a las Otras

El reglamento fija que la dirección de circulación (horario o antihorario) se sortea antes de cada ronda, así que el robot no puede asumirla. Equivocarse no cuesta puntos: cuesta la ronda entera, porque el lado por el que hay que pasar cada pilar depende del sentido.

El sistema vivo (`sentido_vuelta.py`) lo resuelve con tres fuentes de distinta calidad, y las trata como tales:

1. **Las líneas de piso vistas por la cámara** (`fijar_por_camara`). Es la primera en llegar: en cuanto la cámara ve una línea de esquina, el color de la que tiene *más cerca* fija el sentido — naranja primero significa horario, azul primero antihorario. Se compromete una sola vez y no se revisa, porque a esa distancia el dato es inequívoco.

2. **El TCS3472, al frente del vehículo** (`observar_linea`). No mira el color de una línea suelta sino **el orden en que se cruza la pareja** de líneas de una misma esquina. Esa es la única evidencia absoluta del sistema: no depende del yaw del robot ni de interpretar la geometría de la pista. Por eso es la única que puede **corregir un sentido ya comprometido**, y tiene tres salvaguardas medidas en pista:
   * **Marcha atrás no cuenta.** Retroceder sobre una línea la cruza en orden inverso, o sea que afirma el sentido contrario del real.
   * **La pareja tiene que ser de la misma esquina.** Sin una ventana temporal se emparejaba la naranja de una esquina con la azul de la siguiente, y el sentido oscilaba: cinco cambios en una sola corrida.
   * **Desdecir a otra línea exige dos parejas seguidas.** Corregir a la geometría es inmediato, porque la línea es mejor evidencia; contradecir a otra lectura de línea no, porque entonces una de las dos está mal y hace falta desempate.

   Requiere calibrar el orden una sola vez con `calibrar_lineas.py`, empujando el robot una vuelta a mano en un sentido conocido. **Sin esa calibración no se inventa nada: la fuente se ignora por completo.**

3. **La asimetría de las paredes** (`SentidoPorGeometria`). El bloque interior siempre está más cerca que el muro exterior, así que comparar la distancia mínima izquierda contra la derecha da el sentido sin ver ninguna línea. Es la red de seguridad cuando la lona está sucia, hay un reflejo o un pilar tapa la línea.

La jerarquía no es arbitraria: una fuente absoluta corrige a una interpretativa, nunca al revés. Y ninguna de las tres inventa un valor cuando no tiene evidencia — se prefiere no tener dato a tener uno fabricado, porque un sentido equivocado con confianza alta es peor que no tener sentido.

### 5.4 Parámetros de Control y Proceso de Ajuste

Los valores numéricos vigentes en `ronda_abierta.py`, obtenidos empíricamente mediante prueba y error directamente en pista (sin instrumentación de *logging* de datos, por lo que el método de validación fue observacional: repetir vueltas hasta eliminar oscilación visible contra las paredes):

| Parámetro | Valor Vigente | Efecto observado al ajustarlo |
| :--- | :---: | :--- |
| `KP_LATERAL` | `0.14` | Ganancia proporcional del centrado. Valores mayores generaban zigzag (sobrecorrección) en los tramos rectos; valores menores dejaban al coche "flotando" sin corregir a tiempo antes de una curva cerrada. Unificado a `0.14` en `ronda_abierta.py` y `ronda_cerrada.py` (antes `ronda_abierta.py` tenía `0.22`, un valor no probado que quedó desincronizado). |
| `KD_ESTABILIDAD` | `0.12` | Amortiguación derivativa en la Pico 2 (sección 6.2). Compensa el sobregiro que el término proporcional introduce al salir de una curva. |
| `VELOCIDAD_CRUCERO` | `100` | Velocidad de PWM en tramo recto/curva estándar. |
| `VELOCIDAD_PARQUEO` | `60` | Velocidad reducida durante la búsqueda de la posición de estacionamiento final, priorizando precisión sobre velocidad. |
| `TIMEOUT_BUSQUEDA_PARQUEO` | `4.0 s` | Límite de seguridad: si la firma espacial de estacionamiento no coincide en 4 segundos, el sistema fuerza la detención igualmente para no exceder el tiempo de carrera reglamentario. |
| Umbral de distancia de evasión | `45 cm` | Distancia LiDAR a la que se activa la maniobra de esquiva; se eligió para dar margen de reacción mecánica sin iniciar el giro tan temprano que el coche invada el carril contrario de forma innecesaria. |
| Umbral de coincidencia de estacionamiento | `80 mm` | Tolerancia entre la firma espacial inicial y la actual (`match_firma_original`) para considerar que el coche volvió a su punto de partida. |

* **Proceso de ajuste:** El equipo itera cambiando un parámetro a la vez, corriendo 2-3 vueltas consecutivas en la pista de práctica y observando el comportamiento cualitativo (oscilación lateral, choque con paredes, retraso en la reacción a curvas), validado con métricas cuantitativas de la corrida (ver abajo).

#### Métricas de Validación de Rendimiento

Cada corrida de `ronda_abierta.py`/`ronda_cerrada.py` instancia [`registro_metricas.py`](src/pi5/ronda_curvas/registro_metricas.py) (en `ronda_nueva` ese papel lo cumple `telemetria.py`), que escribe un CSV en `logs/` con una fila por barrido de LiDAR procesado (`fase`, `estado`, `heading`, `error_lateral`, `angulo`, `velocidad`) — error lateral promedio/máximo/mediano en mm, porcentaje de ciclos con el servo saturado en su límite físico y número de eventos de emergencia (transiciones a `RETROCESO`).

Formato de salida (ejemplo ilustrativo con datos sintéticos, no una corrida real):

```
Error lateral |e|: promedio 18.4 mm, maximo 96.0 mm, mediana 12.0 mm
Ciclos con angulo saturado en el limite fisico del servo: 4/812 (0.5%)
Eventos de emergencia (entradas a RETROCESO): 1
```

Esto reemplaza la validación puramente observacional: dos corridas con el mismo `KP_LATERAL` se pueden comparar por error lateral promedio y saturación del servo en vez de una impresión subjetiva de "se vio mejor". *Nota de estado:* la herramienta se agregó a este repositorio pero todavía no se ha corrido en pista con el hardware real — los CSV de corridas reales del equipo, una vez capturados, reemplazarán este ejemplo.

---

### 5.5 Reconocimiento de Pilares por Red Neuronal (acelerador Hailo)

La sección 4.5 termina con un límite que no se resuelve con software: **el LiDAR ve el bulto de un pilar hasta unos $1400\,\text{mm}$ y la cámara solo le pone color desde unos $1100\,\text{mm}$**, y en esa franja el robot sabe que hay algo pero no de qué lado pasarlo. Se probaron dos respuestas desde el control y las dos empeoraron el resultado (sección 9.3). La conclusión registrada entonces fue que **el corte es geométrico, no de calibración**, y que la salida tenía que ser óptica o de método, no de umbrales.

El acelerador es esa salida por la vía del método: en vez de decidir el color con un umbral HSV fijo, lo decide una red entrenada con imágenes de la propia pista en las condiciones de luz reales.

#### Qué sustituye, y qué no

Conviene acotarlo, porque un acelerador de IA invita a suponer que el vehículo entero pasó a funcionar por red neuronal, y no es el caso:

| Función | Antes | Ahora |
| :--- | :--- | :--- |
| **Color y posición de los pilares** | Máscara HSV sobre el frame | **YOLOv8n sobre el Hailo-8** |
| Líneas de pista (conteo de vueltas) | HSV + TCS3472 | **Sin cambios** |
| Paredes, esquinas y bultos | Agrupamiento geométrico del LiDAR | **Sin cambios** |
| Rumbo y guiñada | MPU6050 integrado en la Pico 2 | **Sin cambios** |

Que las tres últimas filas no cambien es deliberado: son las que sostienen el centrado y el conteo de vueltas, y ya están medidas y validadas en pista. El pilar era el único punto donde la percepción dependía de un umbral sensible a la iluminación del pabellón.

#### El dataset: por qué se capturó así

El dataset se toma con un panel web servido por la propia Raspberry Pi, al que el equipo se conecta desde el teléfono con la pista montada. La decisión de método está escrita en el propio panel, debajo del botón:

> *«Mueve el robot durante la tanda: diez fotos de una escena quieta son un solo dato repetido.»*

Esa frase es el criterio entero. Una tanda de 25 disparos con el robot inmóvil produce 25 archivos y **un** dato; movido, produce 25 puntos de vista distintos del mismo pilar. El contador del panel se lleva **por condición de luz**, no en total, porque lo que se cubre no es volumen sino variedad de iluminación:

| Condición de luz | Imágenes | Tandas | Evidencia de captura |
| :--- | :---: | :---: | :---: |
| `aula_apagada` | $225$ | $20$ | Panel de captura en aula apagada |
| `persiana_cerrada` | $275$ | $35$ | Panel de captura con persiana cerrada |
| `aula_encendida` | $534$ | $7$ | Panel de captura en aula encendida |
| **Total capturado** | $\mathbf{1034}$ | $\mathbf{62}$ | |

Las tres condiciones no son decorativas: son los tres regímenes en que el mismo pilar da lecturas HSV distintas. Con el `aula_apagada` el frame es casi negro y el pilar apenas se separa del fondo; con `persiana_cerrada` aparece un reflejo especular en el piso; y en `aula_encendida` el color satura. **Ese rango es exactamente lo que un umbral fijo no puede cubrir a la vez**, y es la razón de que la calibración HSV hubiera que rehacerla en cada jornada.

| Aula apagada — el pilar apenas se separa del fondo | Persiana cerrada — reflejo especular en el piso | Aula encendida — el color satura |
| :---: | :---: | :---: |
| Condicion aula apagada | Condicion persiana cerrada con reflejo | Condicion aula encendida |

El reparto de tandas también dice algo: `aula_encendida` tiene $534$ imágenes en solo $7$ tandas y `persiana_cerrada` $275$ en $35$. Las tandas cortas y numerosas son de sesiones en las que se reposicionó el robot entre una y otra; las largas, de barridos continuos. **La condición peor iluminada es la que más tandas distintas tiene**, que es donde más falta hace la variedad de punto de vista.

#### Del dataset capturado al dataset entrenable

De las $1034$ capturadas se etiquetaron **$758$** en formato YOLO, repartidas así:

| Partición | Imágenes | Etiquetas |
| :--- | :---: | :---: |
| `train` | $624$ | $624$ |
| `val` | $134$ | $134$ |
| **Total etiquetado** | $\mathbf{758}$ | $\mathbf{758}$ |

Son **dos clases**: `0 = pilar_rojo` y `1 = pilar_verde`, con $830$ instancias anotadas en total.

> **Hay un desequilibrio de clase que conviene tener presente:** $462$ instancias de `pilar_rojo` contra $368$ de `pilar_verde`, un $25\,\%$ más de rojo. No es intencionado —sale de cómo quedaron montadas las escenas— y es justo el tipo de sesgo que puede hacer que el modelo prefiera la clase mayoritaria cuando la imagen es ambigua. Dado que **pasar un pilar por el lado equivocado termina el recorrido**, es un punto a vigilar en la validación.

#### El modelo y su conversión al Hailo-8

| Parámetro | Valor |
| :--- | :--- |
| Arquitectura | **YOLOv8n**, 2 clases |
| Entrada | RGB $640 \times 640$, redimensionado con proporciones y relleno $(114,114,114)$ centrado |
| Normalización | $/255$ **incluida dentro del modelo** — se entregan píxeles de 0 a 255 sin dividir |
| Posprocesado | NMS de YOLOv8 vía HailoRT **en CPU**: umbral de puntuación $0.2$, IoU $0.7$, hasta $100$ detecciones por clase |
| Decodificadores de caja | Tres, en *strides* $8 / 16 / 32$, con `regression_length` $= 16$ |
| Arquitectura objetivo | `hailo8` (26 TOPS) — **no** `hailo8l` |
| Calibración de cuantización | $256$ imágenes reales de entrenamiento, selección reproducible (DFC 3.34.0) |
| Artefacto desplegable | [`pilares_v0.hef`](src/pi5/red_pilares/pilares_v0.hef), $4.2\,\text{MiB}$ |

Dos decisiones de la conversión merecen explicación, porque las dos se tomaron después de que algo fallara:

* **Se reconstruyen las seis salidas de detección desde el ONNX**, evitando las operaciones finales que provocaban errores de asignación en el HAR anterior. El posprocesado no viaja dentro del grafo: se delega en la estructura NMS de Hailo Model Zoo adaptada a dos clases.
* **La calibración usa imágenes reales de pista, no las ficticias.** El repositorio de conversión traía un `calib_data` de relleno; cuantizar con él habría ajustado los rangos numéricos a una distribución de píxeles que el robot nunca ve.

Todo lo necesario para reproducir la conversión está en [`src/pi5/red_pilares/`](src/pi5/red_pilares/README.md): el HEF, los pesos entrenados, la receta de cuantización y la configuración de NMS.

#### Estado de validación

Aquí es donde conviene ser preciso, porque hay dos cosas distintas y solo una está medida:

| | Estado |
| :--- | :--- |
| **El acelerador funciona en la Pi 5** | ✅ Medido en banco el 14-09-2026: $310\,\text{FPS}$ y $12.8\,\text{ms}$ de latencia de *pipeline*. |
| **El modelo de pilares compila y produce un HEF válido** | ✅ Convertido el 15-09-2026 para `hailo8`, con calibración sobre imágenes reales. |
| **El modelo detecta pilares con precisión suficiente en pista** | ⬜ **Pendiente.** |

La tercera fila es la que decide si esto sirve, y todavía no tiene número. El propio documento de conversión lo dice sin rodeos: *la conversión no demuestra la precisión de detección*. Falta ejecutar el HEF en la Raspberry con HailoRT y evaluarlo contra las $134$ imágenes de validación y contra la cámara en vivo.

> **La medida que cierra esta sección** es la comparación en pista contra la máscara HSV en las mismas corridas: tasa de acierto de color por pilar y **alcance efectivo en milímetros**. Ese segundo número es el que diría si la red mueve el límite de $1100\,\text{mm}$ de la sección 4.5 o solo lo hace más estable frente a cambios de luz. Hasta tenerlo, esta sección documenta una capacidad **instalada y convertida**, no una mejora demostrada; y por eso la ronda sigue corriendo hoy con la vía HSV, que sí está validada en pista.

---

## 6. Capa de Control de Bajo Nivel (Raspberry Pi Pico 2)

### 6.1 Firmware Embebido y Sincronización No Bloqueante

La capa de control inferior ejecuta una arquitectura síncrona no bloqueante sobre MicroPython. El núcleo del sistema utiliza un objeto `select.poll()` registrado sobre el flujo de entrada estándar (`sys.stdin`) para procesar las tramas seriales enviadas por la Raspberry Pi 3B a una frecuencia de ciclo alta sin interferir con los procesos críticos de integración inercial y generación de PWM.

### 6.2 Implementación Matemático-Inercial

Para contrarrestar los efectos dinámicos del subviraje y estabilizar el coche ante irregularidades de la pista o vibraciones estructurales del chasis de LEGO, la Pico 2 ejecuta un bucle de compensación derivativa inercial activa.

La ecuación en lazo cerrado que calcula la posición angular final del servomotor responde a:

$$\theta_{\text{servo}} = 90^\circ + \theta_{\text{objetivo}} - (\omega_z \cdot K_D)$$

Donde:

* $90^\circ$ (constante `CENTRO` en `src/pico/main.py`) representa el punto central calibrado por software para la marcha en línea recta del servomotor. Este valor se validó y corrigió en pista: el equipo probó inicialmente $180^\circ$ como centro (ver historial de versiones, sección 2.1) y lo revirtió a $90^\circ$ tras detectar desalineación física del servo con ese offset.
* $\theta_{\text{objetivo}}$ es el ángulo macro de guiado espacial solicitado dinámicamente por el script de la Raspberry Pi.
* $\omega_z$ es la velocidad angular instantánea sobre el eje de rotación vertical (Yaw), obtenida tras sustraer el offset estático de calibración: 

$$\omega_z = \text{Gyro}_{z} - \text{Offset}_{z}$$

* $K_D$ es la ganancia derivativa de amortiguación inercial calibrada en $0.12$, encargada de absorber momentos angulares bruscos en curvas.

### 6.3 Funciones Maestras de Control Físico

```python
# Funciones clave extraídas literalmente de src/pico/main.py

# Límites de giro del servo calibrados en pista
CENTRO = 90
LIMITE_DER = 70    # Máximo giro a la derecha
LIMITE_IZQ = 115   # Máximo giro a la izquierda

def mover_servo(angulo):
    # Protegemos el servo usando los límites calibrados en lugar de 0 y 180
    angulo = max(LIMITE_DER, min(LIMITE_IZQ, angulo))
    duty = int(1638 + (angulo / 180.0) * (8192 - 1638))
    servo.duty_u16(duty)

def controlar_motor(velocidad_porcentaje):
    """ Parser de puente H para el driver TB6612FNG con modulación de velocidad """
    if velocidad_porcentaje > 0:
        bin1.value(1)
        bin2.value(0)
        vel = max(0, min(100, velocidad_porcentaje))
    elif velocidad_porcentaje < 0:
        bin1.value(0)
        bin2.value(1)
        vel = max(0, min(100, abs(velocidad_porcentaje)))
    else:
        bin1.value(1)
        bin2.value(1)
        vel = 0
        
    duty_u16 = int((vel / 100.0) * 65535)
    pwmb.duty_u16(duty_u16)

```

### 6.4 Algoritmo de Lectura Serial y Control Inercial Co-Procesado

El bucle principal regula las restricciones de la geometría de dirección física y transmite ráfagas de telemetría inercial acumulada cada $50\,\text{ms}$ para el conteo predictivo de vueltas:

```python
# Calibración del offset del giroscopio al arrancar (src/pico/main.py)
# Promedia 100 muestras (~1s) para eliminar el bias estático del MEMS
giro_z_offset = 0.0
for _ in range(100):
    try:
        giro_z_offset += sensor.get_gyro_z()
    except: pass
    time.sleep(0.01)
giro_z_offset /= 100.0

# Segmento del bucle de ejecución de bajo nivel (src/pico/main.py)

while True:
    try:
        tiempo_actual = time.ticks_ms()
        dt = time.ticks_diff(tiempo_actual, ultima_lectura) / 1000.0
        ultima_lectura = tiempo_actual
        
        # Extracción y filtrado del ruido estático del giroscopio
        try:
            velocidad_z = sensor.get_gyro_z() - giro_z_offset
        except:
            velocidad_z = 0.0
            
        # Filtro de banda muerta para evitar la deriva acumulativa (Drift)
        if abs(velocidad_z) > 0.15:
            angulo_acumulado += velocidad_z * dt

        # Monitoreo serial asíncrono sin bloqueo de hilos
        if poller.poll(0):
            linea = sys.stdin.readline().strip()
            if linea:
                try:
                    partes = linea.split(',')
                    if len(partes) == 2:
                        velocidad_comandada = int(partes[0])
                        angulo_objetivo = float(partes[1])
                except:
                    pass

        # Aplicación de ley de control inercial amortiguado (Centro en 90°)
        angulo_servo = CENTRO + angulo_objetivo - (velocidad_z * KD_ESTABILIDAD)
        
        # Límites estrictos de protección mecánica del chasis Ackermann
        # (Saturación segura: LIMITE_DER = 70°, CENTRO = 90°, LIMITE_IZQ = 115°)
        angulo_servo = max(LIMITE_DER, min(LIMITE_IZQ, angulo_servo))
        mover_servo(angulo_servo)
        
        # Control dinámico de la etapa de potencia de tracción
        if velocidad_comandada == 0:
            controlar_motor(0)
        else:
            controlar_motor(velocidad_comandada)

        # Transmisión de telemetría de odometría inercial hacia la Pi 3B
        if time.ticks_diff(tiempo_actual, ultimo_envio_telemetria) > 50:
            sys.stdout.write(f"IMU:{angulo_acumulado:.2f}\n")
            ultimo_envio_telemetria = tiempo_actual

        time.sleep(0.005)
        
    except KeyboardInterrupt:
        controlar_motor(0)
        stby.value(0)
        mover_servo(CENTRO)  # Retornar a línea recta (90°) en caso de parada
        break
```

---

## 7. Geometría de Dirección y Movilidad Mecánica

### 7.1 Cinemática del Sistema de Dirección Ackermann y Calibración Real

El chasis diseñado en *BrickLink Studio* adopta de forma estricta la geometría de dirección tipo **Ackermann**. El principio fundamental de este mecanismo radica en evitar que las ruedas delanteras se deslicen lateralmente al trazar una curva, permitiendo que la rueda interior gire un ángulo mayor que la rueda exterior, ya que describe un radio de curvatura más cerrado respecto al centro instantáneo de rotación (CIR).

La ecuación cinemática que rige las restricciones geométricas de nuestro chasis LEGO se ha calibrado utilizando las mediciones físicas reales del prototipo de producción (V2):

* **Ancho de la vía ($w$):** $115\,\text{mm}$
* **Batalla / Distancia entre ejes ($l$):** $136\,\text{mm}$
* **Ancho de los neumáticos:** $36\,\text{mm}$
* **Dimensiones totales del robot:** $138\,\text{mm}$ de ancho $\times$ $242\,\text{mm}$ de largo **medidas con regla** (antes se documentaban 125 x 222 aproximados) — dentro del límite reglamentario de $300\times200\,\text{mm}$ de WRO Future Engineers 2026 con margen amplio en ambos ejes.

$$\cot(\delta_o) - \cot(\delta_i) = \frac{w}{l} = \frac{115\,\text{mm}}{136\,\text{mm}} = 0.845$$

Donde:
* $\delta_o$ es el ángulo de orientación de la rueda directriz exterior.
* $\delta_i$ es el ángulo de orientación de la rueda directriz interior.
* El factor constante de **$0.845$** es integrado directamente en la matriz de transferencia de control de la Raspberry Pi Pico 2 para ajustar dinámicamente el pulso de PWM enviado al Geekservo de dirección, garantizando giros limpios con cero subviraje o pérdida de tracción por fricción estática destructiva en las curvas de la WRO.

### 7.2 Renderizado del Chasis de Producción (V2, compartido con la V3)
A continuación se presenta el modelo CAD estructural del vehículo libre de actuadores y masa suspendida electrónica, aislando los componentes cinemáticos esenciales para la validación de la rigidez torsional del chasis. El archivo fuente reproducible (`.io` de BrickLink Studio) y el listado completo de las 83 piezas Technic están en [`models/Chasis-LEGO-V2/`](models/Chasis-LEGO-V2/README.md):

<p align="center">
  Chasis LEGO V2 - Modelo CAD BrickLink
</p>

### 7.3 Límites Angulares Calibrados y Protección Mecánica

Para salvaguardar la integridad de las articulaciones, uniones y vigas de LEGO contra esfuerzos de torsión excesivos generados por el servomotor de alta velocidad, se implementaron límites de saturación estricta por software en `src/pico/main.py`.

El rango operativo del actuador Geekservo se restringe a los siguientes umbrales mapeados en el firmware de la Raspberry Pi Pico 2:

| Ángulo Límite Derecho (Giro Máximo) | Centro Geométrico Calibrado | Ángulo Límite Izquierdo (Giro Máximo) |
| :---: | :---: | :---: |
| **70°** (`LIMITE_DER`) | **90°** (`CENTRO`) | **115°** (`LIMITE_IZQ`) |
| *Restricción estricta ante comandos de giro a la derecha (−20° desde el centro).* | *Alineación de marcha lineal en pista.* | *Restricción estricta ante comandos de giro a la izquierda (+25° desde el centro).* |

> **Por qué el rango no es simétrico:** a diferencia de un servo genérico, el `base_servo` y las manguetas Ackermann del chasis LEGO tienen una holgura mecánica ligeramente distinta a cada lado por tolerancias de ensamblaje entre piezas. En vez de forzar un rango simétrico en software (que arriesgaría forzar la articulación física contra su tope mecánico de un lado), el equipo calibró cada límite de forma independiente probando el giro máximo real del prototipo, documentado fotográficamente abajo.
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

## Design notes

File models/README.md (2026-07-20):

# Modelos 3D y CAD del Chasis

Esta carpeta documenta las dos generaciones del chasis del vehículo. La justificación de ingeniería completa del cambio de una a otra (mitigación de resonancia en la cámara, reducción de masa del 23.37%, reconfiguración rápida en boxes) está en la sección **3.1 y 3.4** del [README principal](../README.md).

| Carpeta | Prototipo | Estado | Contenido |
| :--- | :---: | :---: | :--- |
| [`Chasis-LEGO-V2/`](Chasis-LEGO-V2/README.md) | **V2 — 613 g** | ✅ Producción actual | Archivo CAD reproducible (`.io` de BrickLink Studio), render y listado de las 83 piezas Technic. |
| [`V1/`](V1/README.md) | V1 — ≈800 g | 🗄️ Archivado | STL originales del chasis monocasco impreso en 3D, catálogo de piezas y guía de ensamblaje/impresión. |

> **Por qué se conservan ambas:** el histórico V1 documenta el proceso real de iteración del equipo (relevante para el criterio de Pensamiento Sistémico de la rúbrica), y varias piezas de dirección/tracción diseñadas ahí (`Eje_llanta`, `Base_llanta`) siguen siendo referencia de diseño válida.

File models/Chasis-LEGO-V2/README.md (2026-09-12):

# Chasis V2 — LEGO Technic (Prototipo de Producción Actual)

Este es el archivo CAD **fuente y reproducible** del chasis de producción actual (613 gramos), modelado en **[BrickLink Studio](https://www.bricklink.com/v3/studio/download.page)** (software gratuito).

<p align="center">
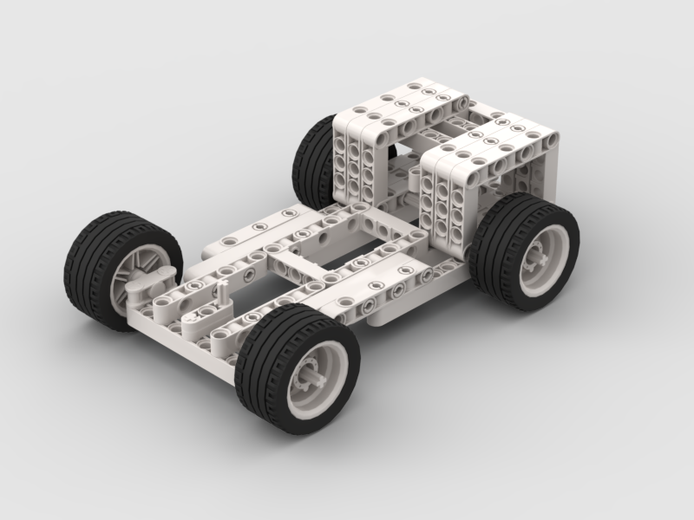
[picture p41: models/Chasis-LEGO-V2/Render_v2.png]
Chasis LEGO V2 - Render CAD BrickLink Studio
  
</p>

* **`Chasis-V2.io`**: Abrir con BrickLink Studio para inspeccionar el modelo pieza por pieza, generar la vista explosionada de ensamblaje o exportar el listado oficial de piezas con miniaturas.

## Inventario de Piezas (83 piezas totales)

Extraído directamente de la geometría del archivo `.io` (color LDraw `15` = Blanco para la estructura; las llantas usan el color interno de la pieza compuesta). El **Design ID** es el identificador único de BrickLink/LDraw — con él cualquier equipo puede localizar la pieza exacta en [BrickLink Parts Catalog](https://www.bricklink.com/catalogList.asp) para reproducir el chasis sin ambigüedad.

| Design ID | Cantidad | Pieza (identificación) |
| :---: | :---: | :--- |
| `2780` | 36 | Technic Pin con reborde de fricción y ranura central (conector estructural principal de las vigas) |
| `64179` | 8 | Technic Pin largo con reborde de fricción y doble ranura central |
| `43093` | 5 | Technic Axle Pin (pin-eje híbrido, conecta viga con eje motriz) |
| `bl_56145c01` | 4 | Conjunto Rueda + Neumático (una por esquina, tracción y dirección) |
| `40490` | 4 | Conector Technic (ver miniatura en Studio) |
| `32123a` | 4 | Technic Bush 1/2 (buje espaciador corto, reduce fricción axial) |
| `2391` | 4 | Technic Bush (buje espaciador estándar) |
| `87083` | 2 | Technic Pin largo con fricción (variante 3L) |
| `6632` | 2 | Technic Liftarm / conector de dirección |
| `44294` | 2 | Technic Liftarm |
| `41239` | 2 | Technic Liftarm |
| `32556b` | 2 | Technic Beam (viga estructural larga) |
| `32525` | 2 | Technic Beam (viga estructural) |
| `32524` | 2 | Technic Beam (viga estructural) |
| `32184` | 2 | Technic Steering Arm (brazo de dirección — geometría Ackermann, uno por rueda directriz) |
| `4519` | 1 | Technic Axle 3L (eje corto) |
| `32316` | 1 | Technic Liftarm angular |

> **Nota de trazabilidad:** Algunas piezas de la tabla se listan con nombre genérico ("ver miniatura en Studio") porque no tenemos el catálogo oficial de BrickLink instalado en el equipo que documenta — para evitar reportar un nombre incorrecto, preferimos dejar el Design ID exacto (100% verificable abriendo el `.io`) antes que adivinar el nombre comercial. Los Design ID marcados con razonamiento de ingeniería (Steering Arm, Axle Pin, bujes) sí están descritos porque son piezas clave para la cinemática Ackermann documentada en la sección 7 del README principal.

## Por qué migramos de piezas impresas en 3D a LEGO Technic puro

Ver la justificación completa de ingeniería (mitigación de resonancia en la cámara, reducción de masa del 23.37%, reconfiguración rápida en boxes) en la sección **3.1 y 3.4** del [README principal](../../README.md). El diseño anterior (V1, impreso en 3D) está archivado en [`models/V1/`](../V1/README.md).

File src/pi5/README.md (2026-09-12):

# `src/pi5` — Ronda de obstáculos para la Raspberry Pi 5

Reescritura del cerebro del robot para la Pi 5. **No toca nada de `src/pi3B`**:
es un paquete aparte, con su propia configuración, sus propios drivers y sus
propias pruebas. La Pi 3B sigue arrancando exactamente igual que antes.

```
src/pi5/
  ronda_abierta/
    prueba_abierta.py          prueba independiente (copia de la Raspi)
    ronda_abierta.py           implementación modular existente
  ronda_curvas/                copia de trabajo de la Raspi para la ronda de curvas
  comun/lidar_driver.py        driver del RPLIDAR C1 (copiado tal cual: está probado)
  herramientas/calibrar_suelo.py
  legacy/
    ronda_nueva/               implementación modular archivada
    ronda_cerrada/             implementación anterior archivada
  herramientas/
    calibrar_desde_muros.py    homografía con las paredes, sin colocar nada
    calibrar_suelo.py          cobertura del montaje y homografía con pilares
    capturar_pareja.py         una correspondencia pilar-LiDAR por pose
    diag_arranque.py           comprobación de los tres sensores, sin mover
    diag_cerca.py              qué ve el LiDAR a menos de 600 mm, pasivo
    diag_eco_volante.py        si la propia rueda entra en el barrido
    diag_mastil.py             mide la oclusión fija y propone la máscara
    diag_pilares.py            sesgo cámara-LiDAR sobre un poste real
    bench_vision.py            coste por cuadro y cadencia real de la visión
    reescalar_camara.py        cambia la resolución sin perder la calibración
```

## Código archivado

`legacy/ronda_nueva/` y `legacy/ronda_cerrada/` son las dos implementaciones
anteriores de Pi 5. Se mantienen para consulta y reproducción, pero no son los
programas de trabajo actuales. Sus imports internos no se modificaron: para
reproducir sus comandos históricos desde el repositorio, primero entra en
`src/pi5/legacy/`. El script `deploy.sh` también las toma desde esta carpeta y
las instala con sus nombres históricos, sin mezclar el código archivado con
`ronda_abierta/` o `ronda_curvas/`.

## Código recibido de la Raspberry Pi

Además del código archivado, se preservan dos códigos recibidos directamente de
la Raspi:

- `ronda_abierta/prueba_abierta.py` es la copia sincronizada de
  `/home/pi/prueba_abierta.py` en la Pi 5: una prueba independiente para la
  ronda abierta. Usa el LiDAR en `/dev/ttyUSB0`, la Pico en `/dev/ttyACM0` y
  el botón de inicio en GPIO 21.
- `ronda_curvas/` contiene el conjunto de módulos usado en la Raspi para la
  ronda con cámara y curvas. Es una copia completa del código Python de
  `/home/pi/ronda_curvas` en la Pi 5; su punto de entrada es
  `ronda_camara.py`.

`ronda_curvas/` incluye sus módulos de visión, LiDAR, geometría y pruebas. No
incluye los CSV de `logs/` ni `__pycache__/`, porque son datos generados al
correr el robot. Consulta su README antes de desplegarla: requiere el hardware
y las librerías de Raspberry Pi. No sustituye a `ronda_nueva/`, que sigue
siendo la implementación modular de Pi 5.

---

## 1. El cambio de fondo

En la versión de la Pi 3B, **un pilar interrumpía la conducción**: la máquina
de estados saltaba a `APROXIMACION`, luego a `SOBREPASO`, luego a `RECENTRADO`,
y el seguimiento de pared se apagaba mientras tanto. Medido sobre los CSV del
equipo, evadir se llevaba el **45–52 % de la ronda** —más que girar esquinas— y
la eficiencia de rumbo caía al 6–23 % en cuanto había pilares.

Aquí un pilar **no interrumpe nada: mueve el carril**. El robot siempre está
haciendo lo mismo —seguir un perfil de distancia al muro exterior dentro de la
recta— y los pilares son nodos que deforman ese perfil.

Es la idea del **2.º puesto de 2025** (KMIDS), que controla un único
`targetOuterWallDistance`, con dos añadidos:

1. El offset objetivo se calcula desde la posición **medida** del pilar, no de
   una tabla de cuatro constantes. Con la cámara dando milímetros no hace falta
   suponer dónde está el poste.
2. Entre consignas hay una **rampa**, no un escalón, y la rampa se dimensiona
   con la capacidad real de maniobra del chasis.

Del **1.er puesto** (`ejm22`) se toma la otra idea central: el **polígono de
espacio libre**. Se aísla el trozo de lona sobre el que el robot está parado y
se rellena su contorno; a partir de ahí, «¿este blob está apoyado en la pista?»
es un `AND` de dos máscaras.

---

## 2. Lo que hace la cámara nueva posible

Con la cámara alta y trasera, casi todo lo que importa toca el suelo dentro del
cuadro. Una **homografía 3×3** convierte el punto de contacto de cada blob en
(x, y) en milímetros del marco del robot. Eso cambia tres cosas de raíz:

| Problema conocido | Cómo lo resuelve |
| --- | --- |
| El plano del LiDAR **pasa por encima** del pilar a partir de cierta distancia (el rojo a 1088 mm no se veía) | La cámara lo mide igual de bien a 400 que a 1800 mm |
| El pilar se apagaba a una mediana de **216 mm** por la puerta angular de 15° | El criterio pasa a ser el ancho físico en mm, que no depende de la distancia |
| El sesgo de guiñada de **+3,57°** gastaba el 36 % de la puerta de fusión | Cámara y LiDAR hablan en mm: asociar es el vecino más cercano |
| El sentido de giro y el conteo de vueltas | Tres evidencias: las líneas vistas **con la cámara**, el **TCS3472** ya reconectado y adelantado al eje, y la asimetría de paredes |

Si todavía no hay homografía, la visión **sigue funcionando**: estima la
distancia por la altura aparente del poste (100 mm) y el bearing por la
columna. Peor, pero utilizable el mismo día que montes la cámara.

---

## 3. Lo que el sorteo oficial obliga a tener en cuenta

Leyendo el randomizer oficial de la temporada (`Future_Engineer_2025_Randomizer`)
aparecen dos hechos que cambian el dimensionado y que no se deducen del
reglamento a secas:

- **Cuando una recta lleva dos señales, son siempre p1 y p3.** Nunca dos
  adyacentes. O sea **953 mm** entre ellas, no 480.
- Las dos filas laterales están a **380 y 574 mm** del muro exterior.
  (380 − 50 = 330 ≈ los 333 mm de `narrowest_gap_wall_to_pillar_mm` del equipo:
  cuadra con la escala de 1 px = 1,5 mm de la imagen del sorteo.)
- Las tres posiciones longitudinales caen a **1000 / 1500 / 2000 mm** del muro
  de enfrente, que son exactamente las bandas que usaba el 2.º puesto.

Sin eso se dimensiona el planificador para un caso que el sorteo no puede
producir, y se acaba pidiendo maniobras que el chasis no traza.

---

## 4. Qué se ha validado, y con qué números

Todo esto corre en el escritorio, sin robot:

| Prueba | Resultado |
| --- | --- |
| Paredes por LiDAR, 4 segmentos × 6 poses, ruido 5 mm | 24/24 dentro de 30 mm; rumbo dentro de 3° |
| Homografía: ida y vuelta, DLT, degeneraciones | exacta a 1e-6 |
| **Las 28 disposiciones del sorteo × 2 sentidos** | 56/56 rebasadas por el lado correcto, **33,8 mm** de holgura mínima |
| Lo mismo con 25 mm de ruido en el pilar y 12 en la pose, 3 semillas | 168/168, **24,9 mm** de holgura mínima |
| Vuelta completa simulada, sin pilares | **12 esquinas en 111,5 s** |
| Vuelta completa simulada, **8 pilares** (2 por recta) | **12 esquinas en 130,0 s**, 0 retrocesos, mapa completo |

Los 130 s con ocho postes contra los 111 s vacía son un **+16 %**, no el doble.
Ese número es la medida de que la evasión dejó de costar tiempo.

> El simulador usa el modelo de bicicleta con la batalla (136 mm) y los radios
> de giro **medidos** en el chasis (228 mm a la izquierda, 260 a la derecha), y
> la colisión se calcula contra el rectángulo del robot, no contra su centro.
> No sustituye a la pista: sustituye a *descubrir errores de geometría en la
> pista*. Encontró cuatro, y cada uno habría costado una tarde.

---

## 4bis. Lo que ya se comprobó EN EL ROBOT (04-09, tarde)

Con la cámara nueva ya montada y la Pi 5 encendida, sin mover el robot:

| Comprobación | Resultado |
| --- | --- |
| LiDAR | 10,0 Hz, 461-470 puntos/barrido, **cero barridos perdidos** |
| Paredes ajustadas | frontal 1692 mm, izquierda 540, derecha 427; residuos **4,4 – 6,8 mm** |
| Cámara | 1280×720, suelo = 50 % del cuadro |
| **Visión por cuadro** | **19,2 ms** de mediana (era 49 ms antes de optimizar) |
| Homografía del suelo | **calibrada**: suelo visible de **210 a 3121 mm** |
| Líneas de piso | azul y naranja **detectadas**, proyectadas a 786 y 964 mm |
| Pico | telemetría OK, ultrasonido 1089 mm, `WD:STOP` (normal en reposo) |
| Sensor de color | Reconectado y montado por delante del eje delantero; vuelve a dar `COLOR:` en la telemetría |

**La calibración salió de las propias paredes**, sin colocar un solo pilar:
`herramientas/calibrar_desde_muros.py`. La línea donde el muro toca la lona es
una recta del plano del suelo, el LiDAR la mide en milímetros y la cámara la ve
como el borde superior de la región de suelo. 317 correspondencias repartidas
por todo el ancho del cuadro, ajustadas a 2,3 px de residuo mediano.

Resultado: **altura 177 mm, cabeceo 10,44°, guiñada −3,0°**.

> Dos avisos honestos sobre esos números. (1) El desplazamiento longitudinal de
> la cámara **no es observable** por este método: da igual suponer −220 o +40 mm,
> el residuo apenas cambia. Se dejó en −80. (2) Por eso la altura solo queda
> determinada a **±10 mm**. Medir altura y voladizo con regla cierra las dos
> cosas de golpe; luego `--altura-mm N` reajusta cabeceo y guiñada con la altura
> fija.

La verificación es visual y está en `verif_homografia.jpg`: se proyectan las
tres rectas del LiDAR sobre el cuadro y **caen sobre la base de los muros**.

### La ronda entera, en simulacro sobre sensores reales

`--simulacro` monta la tubería completa —percepción, localización, mapa,
planificador, FSM y CSV— sobre los sensores de verdad y a su ritmo de verdad,
pero **no envía ni una consigna al motor**. Es la prueba más parecida a correr
sin arriesgar el chasis, y se puede lanzar con el robot en el banco:

```bash
timeout -s INT 40 python3 -u -m ronda_nueva.ronda_nueva   --simulacro --arranque-inmediato --sin-parqueo
```

Medido el 04-09 con el robot quieto dentro de la pista:

| | |
| --- | --- |
| Cadencia del ciclo | **10,0 Hz**, la del LiDAR |
| **Ciclo de decisión** | **3,07 ms** de mediana, 4,0 ms máximo |
| — del que percepción LiDAR | 2,98 ms |
| Edad del barrido al decidir | 0,30 ms de mediana, 8,6 ms máximo |
| Sentido de giro | resuelto **en el primer ciclo**, por la línea del piso |
| Falsos positivos de pilar | **0** en 283 ciclos |
| Deriva de rumbo tras compensar | ≤ 5° en 33 s |

`barridos_descartados` marca 27 de 310: no es que el control llegue tarde
—tarda 3 ms— sino que el driver publica algún barrido parcial de más y el buzón
se queda con el nuevo, que es lo correcto.

### Seis cosas que solo aparecieron al conectar el robot

1. **`heading` y `color_piso` del enlace con la Pico son métodos, no
   propiedades**, y el driver del LiDAR expone `hilo_lectura`, no `bucle`. Dos
   errores míos que la simulación no podía ver porque ahí no hay drivers.
2. **La semilla del polígono de suelo caía sobre la cúpula del LiDAR**, que
   asoma por abajo en el cuadro. Movida a `[0.5, 0.72]` y la cúpula enmascarada.
3. **Los umbrales HSV heredados no veían ninguna línea del piso**: pedían
   S ≥ 110 y lo medido sobre la lona real es naranja S 57-88, azul S 52-73.
4. **Reducir el cuadro a la mitad borra las líneas finas.** Al promediar con la
   lona blanca, la naranja pasaba de 2074 píxeles saturados a 30. Por eso los
   pilares van a media resolución y las líneas a resolución completa.
5. **El giroscopio derivaba +20,9 °/s con el robot inmóvil**, perfectamente
   lineal. Ver más abajo: es el hallazgo grave del día.
6. **19 falsos positivos de pilar en 358 ciclos sin ningún pilar en el campo**:
   bultos del muro izquierdo (a 615 mm con el muro a 540) y la propia estructura
   del robot colándose por el borde del sector ciego. Uno llegó a mover el
   carril objetivo. Arreglado con tres filtros: descartar lo que está pegado a
   una pared ajustada, descartar lo que cae dentro de la huella del robot, y no
   dejar que un objeto **sin color** deforme el carril (frena, pero no se le
   elige lado: la regla WRO solo habla de rojo y verde).

### Con la pista montada (04-09, noche)

Con los pilares y el cajón puestos, en dos poses:

| Comprobación | Resultado |
| --- | --- |
| Pilar **rojo** en el carril | **59 detecciones de 59 ciclos**, (208, 1470) mm, **±0 mm** de dispersión |
| — y solo por cámara | el LiDAR **no lo ve** a 1,47 m: su plano le pasa por encima |
| Clasificación en el mapa | lo asigna a la **recta siguiente**, que es donde está (al otro lado de la esquina) |
| Muros del cajón | **59 de 59 ciclos**, (−9, 268) mm |
| Líneas azul y naranja | detectadas en las dos poses |
| Falsos positivos | 0 |

Que el rojo salga **solo por cámara a 1,47 m** es la demostración directa de por
qué se hizo la homografía: es exactamente el agujero del LiDAR que la bitácora
del equipo llevaba documentado.

### Dos trampas de percepción que solo se ven con cosas en el campo

**1. Los delimitadores del cajón del banco son violeta, no magenta.**
Medido: H 127-131, S 85-140, V 34-77. El magenta oficial de WRO (#F702F9) daría
H 150, S 253, V 249 — nada que ver. Peor: ese violeta cae **dentro** del rango
de la línea azul del piso (H 125-132), así que el delimitador se leía como
línea de sentido, y eso habría mandado el robot a dar la vuelta al revés.

Ningún umbral de color los separa con margen. Se distinguen por **geometría**:
se proyectan al suelo el borde de arriba y el de abajo de la mancha, y si el de
arriba se va más de 2,2 veces más lejos (o pasa del horizonte) es que está de
pie, no tumbada. Se probaron antes dos filtros peores —exigir que fuera mucho
más ancha que alta, y mirar si había lona por encima— y los dos fallaban: el
primero descartaba también la línea azul de verdad, y el segundo se colaba
porque por encima del delimitador se ve la lona del otro lado del muro.

Se aceptan los dos rangos de color. **Si en competencia los delimitadores son
los oficiales, hay que revalidarlo allí.**

**2. El `AND` con el polígono de espacio libre perdía los postes pegados al muro.**
Un poste en medio de la lona es un *agujero* del componente de suelo y al
rellenar el contorno queda dentro. Uno pegado al muro del fondo no: es una
*muesca* del borde superior, y el `AND` lo dejaba fuera. Medido en el robot: un
rojo perfectamente visible a 1,4 m, que pasaba todos los filtros de forma y
cuyas dos estimaciones de distancia coincidían al 9 %, se quedaba en **7 píxeles
de 725**.

Ahora se pregunta por la lona que hay **justo debajo de la base**, en una banda
fina y pegada. Cubre los dos casos y es la prueba original del campeón de 2025.

### Lo que queda abierto: la cámara mide un 19 % más lejos que el LiDAR

Sobre el mismo pilar verde, con los dos sensores viéndolo a la vez:

| | |
| --- | --- |
| LiDAR (centroide crudo) | (−137, 694) mm, clúster de **43 mm** |
| Cámara (contacto con el suelo) | (−227, 840) mm |
| Discrepancia | **173 mm de mediana** sobre 49 parejas |

Dos cosas se arreglaron a raíz de esto:

* **`pillar_width_mm` estaba en 100 y son 50.** El clúster del LiDAR mide 43 mm:
  son las señales de 5×5×10 cm del reglamento. Inflaba la corrección de
  centroide de la fusión y gastaba 25 mm de holgura de más en el planificador.
* **La herramienta de calibración ajustaba con el centro óptico nominal (640) y
  la ronda reconstruía con el medido (704,148).** Son 64 px, casi 4° de
  guiñada. Ahora la herramienta escribe la **matriz explícita**, así que no
  pueden desalinearse, y el ajuste mejora a 1,53 px de mediana (era 2,22). La
  guiñada pasa de −3,0° a +0,75°: estaba absorbiendo ese desplazamiento.

Pero el fondo del asunto sigue abierto. Se intentó un **ajuste conjunto**
(paredes + la correspondencia del pilar, con altura, cabeceo, guiñada y los dos
desplazamientos libres) y el resultado **no es de fiar**:

| | residuo de muros | error al pilar | desplazamiento lateral |
| --- | --- | --- | --- |
| Solo paredes | **4,93 px** | 150 mm | 0 (fijado) |
| Conjunto, rejilla gruesa | 8,74 px | 23 mm | 120 mm |
| Conjunto, refinado | 6,78 px | 61 mm | 90 mm |

Para cuadrar el pilar hay que empeorar las paredes y meter 90-120 mm de
desplazamiento lateral entre cámara y LiDAR, que es demasiado para un mástil.
**Con una sola correspondencia de pilar y cinco parámetros libres el problema
está mal condicionado**: el ajuste solo cambia una evidencia por la otra. Por
eso se conserva el ajuste por paredes, que sí está bien condicionado.

**Impacto real, para decidir si urge:** por debajo de 1400 mm la fusión usa la
posición del LiDAR, así que la evasión cercana y la asignación al mapa del poste
que se está rebasando **no se ven afectadas** — se comprobó: el verde a 718 mm
cae en la casilla p3 fila exterior, la correcta. Por encima de 1400 mm manda la
cámara sola, y un pilar a 2 m leería unos 2,4 m: eso sí caería en la casilla
equivocada y estropearía la anticipación, que es de donde sale el tiempo en las
vueltas 2 y 3.

### CERRADO con dos medidas de regla

El equipo midió: **145 mm del lente a la lona**, y el LiDAR a 30 mm del borde
derecho del chasis y 35 del izquierdo — o sea casi centrado, **2,5 mm** del
centro. Eso descarta de plano los 90-120 mm de desplazamiento lateral que pedía
el ajuste conjunto: era ruido de un problema mal condicionado.

Con la altura fijada a 145 y el lateral a −2,5, el ajuste vuelve a estar bien
planteado y solo quedan cabeceo, guiñada y voladizo. Resultado:

| | cámara vs LiDAR (mediana) | confianza de fusión | residuo de muros |
| --- | --- | --- | --- |
| Ajuste inicial (centro óptico nominal) | 198 mm | — | 5,35 px |
| Centro óptico corregido | 173 mm | 0,73 | 4,93 px |
| **Con la altura medida** | **71 mm** | **0,87** | 8,57 px |

**71 mm está por debajo del listón de 80 mm** que la propia herramienta pone
para dar una homografía por buena. Y el suelo pasa a verse desde **74 mm** por
delante, contra 215 antes.

Que el residuo de muros empeore es esperado y se acepta **a propósito**: es un
indicador indirecto — la cámara no mide paredes, eso lo hace el LiDAR — y la
métrica que de verdad importa es dónde pone los pilares. La explicación del
sesgo: la lona justo al pie del muro queda en sombra, cae fuera de
`floor_ranges`, y el borde detectado sale unos píxeles por debajo de la junta
real; el ajuste lo compensaba subiendo la cámara de 145 a 180 mm.

### El montaje, cerrado

Los **tres parámetros de posición están medidos con regla**:

| | |
| --- | --- |
| Altura del lente a la lona | **145 mm** |
| Voladizo (horizontal, del eje del LiDAR al lente, hacia atrás) | **126 mm** |
| Desplazamiento lateral | **−2,5 mm** (el LiDAR a 30 y 35 mm de los bordes del chasis) |

Los **dos de orientación** —cabeceo 9,60° y guiñada 0,50°— se fijaron con las
dos correspondencias cámara-LiDAR directas del mismo instante, y quedan exactas:

* distancia **radial** a un pilar que ven los dos sensores: **1 mm**
* punto de contacto del delimitador magenta contra la recta que el LiDAR mide de
  ese mismo delimitador: **0 mm**

Vale la pena anotar que el voladizo estimado por esas dos evidencias **antes** de
medirlo dio −130, y la regla dijo −126: **4 mm**. Es la validación del método.

Y una regla de método que costó descubrir: **no se ajusta contra el residuo de
muros.** Ese borde tiene un sesgo conocido —la lona al pie del muro queda en
sombra y cae fuera de `floor_ranges`— y por eso el ajuste por paredes pedía
180 mm de altura contra los 145 reales. La cámara no mide paredes; eso lo hace
el LiDAR.

### Lo único que queda, y por qué no es un parámetro

Sobre el pilar quedan ~70 mm de error, **todo lateral**. Ningún parámetro de este
modelo lo corrige, y se comprobó barriendo la guiñada:

| guiñada | error al pilar (rumbo −16°) | error al delimitador (rumbo +22°) |
| --- | --- | --- |
| +1° | 65 mm | 0 mm |
| +5° | **13 mm** | 19 mm |

Un error de guiñada desplazaría los dos por igual. Que corregir uno estropee el
otro significa que el error **depende del rumbo**: es distorsión de lente —el
modelo es pinhole puro con 68° de campo— más el sesgo de centroide de cada
correspondencia.

Se cierra con `calibrar_suelo.py --usar-lidar` y cuatro pilares repartidos: el
DLT ajusta los **ocho** grados de libertad de la homografía y absorbe lo que un
modelo físico de cinco parámetros no sabe expresar. Con 72 mm y la fusión
prefiriendo el LiDAR por debajo de 1,4 m, ya no es urgente.

### El hallazgo grave: la IMU derivaba 20,9 °/s

Con el robot completamente quieto, el rumbo acumulado subía **742° en 36 s**.
Un giro de esquina dura unos dos segundos: la deriva sola metía **42° de error
en cada esquina**. Con eso, ninguna vuelta habría cerrado.

El firmware de la Pico *sí* promedia 100 muestras al arrancar para quitar el
sesgo, pero ese bucle se traga sus excepciones (`except: pass`). Si el I2C aún
no responde —lo normal justo después de alimentar la placa— el offset se queda
en cero y el sesgo crudo entra entero en la integración. La deriva medida es
perfectamente lineal, que es la firma de exactamente eso.

**No se ha tocado el firmware de competición.** La ronda se blinda desde la Pi:
`EnlacePicoNuevo.calibrar_deriva` mide la deriva durante 2,5 s con el robot
quieto, justo antes de arrancar, y la resta linealmente. Verificado en el robot:
de **+20,94 °/s a 0,13 °/s residual**, un factor 160. Si la deriva supera
1 °/s la ronda lo avisa por consola y recomienda reiniciar la Pico.

Merece la pena arreglarlo también en el firmware —contar las muestras que de
verdad se leyeron y reintentar—, pero eso es una decisión tuya: es la placa de
competición.

---

## 4ter. Recalibración del 05-09: máscara del mástil y cámara a 1536×864

Tres cosas, todas medidas en la Pi 5 (`192.168.30.115`, despliegue
`/home/pi/wro_pi5_20260904`) con el robot parado y sin mover un motor.

### La máscara del mástil estaba 22 grados corta, y eso cegaba la parte trasera

`herramientas/diag_mastil.py` (nueva) abre solo el LiDAR y, para cada grado
entero, cuenta **de las veces que ese grado tuvo muestra, en cuántas la
muestra estaba cerca**. El denominador importa: el C1 entrega unos 465 puntos
por vuelta, o sea 1,3 muestras por grado, así que un grado cualquiera se queda
sin muestra en una vuelta de cada cuatro por puro reparto angular. Contra el
total de barridos, hasta una pieza sólida sale al 75 % y parece intermitente.

Con ese criterio, y repetido tres veces:

| | |
| --- | --- |
| arco con eco en el **100 %** de los barridos que lo miraron | **141..194 grados** |
| distancia | 37-72 mm |
| dispersión (p90 − p10) por grado | 2-4 mm |
| el grado 140 | 17 % |
| el grado 195 | 2 % |

Los bordes son limpios, no hay que interpretar nada. Y a 37-72 mm no puede
haber pista: el LiDAR va **al ras del parachoques** y el robot se extiende
222 mm hacia atrás, así que todo lo que devuelve eco ahí es el propio robot.

La máscara heredada de la Pi 3B era `163-195` y **dejaba 141..162 sin tapar**,
justo dentro de `rear_sector_deg` (150-210). Consecuencia, medida en dos
simulacros consecutivos con el robot en el mismo sitio:

| `trasera_min` | máscara 163-195 | máscara 140-195 |
| --- | --- | --- |
| mediana | **40,2 mm** | **1712,9 mm** |
| p10 | 39,0 | 1709,2 |
| máx | 43,2 | 1718,2 |

O sea: el robot creía tener 40 mm detrás **en todos los ciclos de su vida**, y
lo que había era el muro a 1,71 m. `holgura_trasera_min_mm` son 70, así que
cualquier comprobación de seguridad marcha atrás —y el parqueo entero— estaba
leyendo un obstáculo pegado al culo que era su propio mástil. Los demás
sectores no se movieron ni un milímetro (izquierda 562,8; derecha 394,2 →
394,5; corredor 1640,1 → 1640,2), que es la prueba de que el cambio tocó solo
lo que tenía que tocar.

**La máscara es del montaje, no del robot.** En la Pi 3B el mástil estaba a
84-113 mm y ocupaba 163..193; aquí está a 37-72 y ocupa 141..194. Se mide cada
vez que se toca la cámara, y por eso la herramienta existe.

`blind_sectors_deg` se escribe con el **primer y el último grado a tapar**:
`_en_sector` es inclusivo en los dos extremos.

### La cámara a 1536×864, con toda la calibración reescalada

Subir la resolución no es cambiar dos números. Media configuración está en
píxeles del cuadro, y `herramientas/reescalar_camara.py` (nueva) los mueve
todos a la vez:

* `principal_x_px` 704,148 → **844,9776**, `principal_y_px` 360 → **432**. El
  centro óptico está en el mismo punto de la lente; le toca otro píxel.
* **`ground_homography.matrix`**, componiéndola con la escala:
  `H_nueva = H_vieja @ diag(1/s, 1/s, 1)`. Esto es lo que de verdad podía
  arruinar el mapa en silencio: sin tocarla, cada píxel se proyectaría a 1,2
  veces su distancia real. Medido, no razonado: el píxel del centro-abajo pasa
  de proyectarse a (10,6, 121,3) mm a **caer por encima del horizonte** y
  devolver `None`. Hay un test de regresión que mira el mismo punto del mundo a
  dos resoluciones y exige el mismo milímetro.
* los umbrales de visión en píxeles: las **áreas** con `s²` (`min_area_px`
  90 → 130, `magenta_min_area_px` 250 → 360, `line_min_area_px` 400 → 576) y
  las **longitudes** con `s` (`min_height_px` 12 → 14, `morph_open_px` y
  `morph_close_px` 6 → 7, `line_polygon_dilate_px` 11 → 13). Si no, cambia la
  sensibilidad de la detección y los tiempos dejan de ser comparables.

Lo que **no** cambia: `hfov_deg` (es óptica) y `raw_sensor_size` (es el modo
del sensor). Esto último es la trampa: el IMX708 tiene un modo nativo
1536×864 que **recorta a 3072×1728 y tira un tercio del ángulo**. Pidiendo
`main` 1536×864 con `raw` fijado en 2304×1296, el `ScalerCrop` sigue siendo
`(0, 0, 4608, 2592)`, exactamente igual que a 1280×720: **el campo no cambia,
solo la rejilla de píxeles**. Verificado en la Pi antes de tocar nada.

### Lo que cuesta, medido con la tubería real

`herramientas/bench_vision.py` (nueva) procesa **dentro del callback de la
cámara**, igual que la ronda, porque lo que interesa no es el coste por cuadro
sino la cadencia que ve la fusión: si un cuadro pasa del periodo, no se acumula
retraso, se pierden cuadros.

| | 1280×720 | 1536×864 |
| --- | --- | --- |
| mediana | 19,3 ms | 33,1 ms |
| p90 | 19,4 | 33,6 |
| **entrega real** | **30,0 Hz** | **28,8 Hz** |

Pasa del presupuesto de 33,3 ms por 0,3, y el precio son 1,2 Hz: 4 %. Para un
control que decide al ritmo del LiDAR (9 Hz) no es nada.

`process_scale` **no es la palanca**: a 1536×864, bajarlo de 0,5 a 0,35 solo
ahorra 2,3 ms. El coste vive en la pasada a resolución COMPLETA de las líneas
de piso, que es justo la que no se puede reducir (a media resolución la franja
naranja pasaba de 2074 px a 30).

### El LiDAR no tenía latencia que quitar, y la cámara nueva no se la añadió

Medido en el CSV de dos simulacros (`lidar_edad_ms`, la edad real del barrido
cuando el control lo consume):

| | 1280×720 | 1536×864 |
| --- | --- | --- |
| mediana | 0,30 ms | **0,30 ms** |
| media | 0,43 | 0,48 |
| p90 | 0,40 | 0,60 |

Los 0,1 ms que están apuntados en la bitácora de la migración se midieron con
`diag_latencia` —sin Pico y sin lazo de control—; con la ronda entera montada
el número es 0,3 ms de mediana. **No hay latencia que recortar**: son un tercio
de milisegundo contra un periodo de LiDAR de 108 ms, y lo que queda es la
latencia de despertar un hilo. Lo que sí se puede leer aquí es que subir la
cámara **no** ha estropeado el barrido, que era el riesgo real.

`vision_edad_ms` sí sube, de 41,7 a 50,2 ms de mediana (p90 64,6, máx 83,3),
todavía dentro de los 120 ms de `max_camera_lidar_age_s`. A 200 mm/s eso son
10 mm de desplazamiento entre el cuadro y el barrido, contra 8,3 antes:
1,7 mm más, despreciable al lado de los 36 mm de sesgo cámara-LiDAR.

### Un cabo suelto que deja abierto la máscara nueva

Con 140..195 tapado, de `rear_sector_deg` (150-210) solo sobreviven 15 grados,
todos por el lado izquierdo. Eso es la física —el robot no puede verse la
espalda—, pero deja el sector trasero torcido: la ventana honesta son dos
lóbulos, `110..140` y `196..230`, y el bloque solo admite un sector. **No se ha
tocado** porque solo lo usa `estacionamiento.py`, que sigue con
`parking_ready: false` y nunca se ha ejercitado con motores; hay que decidirlo
antes de estrenar el parqueo.

---

## 5. Lo primero que hay que hacer, en orden

### 5.1 Elegir altura y cabeceo **mientras montas la cámara**

```bash
python3 herramientas/calibrar_suelo.py --cobertura --altura-mm 400 --cabeceo-deg 28
```

No necesita robot ni cámara. Dice desde cuántos mm por delante empieza a verse
el suelo y hasta dónde llega. Prueba varias combinaciones antes de apretar los
tornillos.

**Objetivo:** que el alcance en el eje pase de **1,6 m**. Por debajo de eso el
mapa solo ve el pilar inminente y pierde la ventaja de anticipar los otros dos,
que es de donde sale la mayor parte del tiempo que se gana.

### 5.2 Medir el bloque `chassis` con regla

Van **tres valores de montaje comprobados y tres desviados**. Antes de fiarte
de ninguna geometría, repasa con regla: `wheelbase_mm`, `width_mm`,
`length_mm`, `rear_overhang_mm` y `lidar_to_*_edge_mm`. Luego pon
`calibration.chassis_measured: true`.

### 5.3 Calibrar la homografía

**Ya está hecha** (ver 4bis), pero hay que repetirla cada vez que se toque el
mástil. Dos métodos, y el primero no necesita colocar nada:

```bash
# con las paredes: basta con poner el robot en la pista
python3 herramientas/calibrar_desde_muros.py --dibujar /tmp/verif.jpg --escribir
# y, si ya mediste la altura con regla:
python3 herramientas/calibrar_desde_muros.py --altura-mm 180 --escribir

# con pilares, si quieres una segunda opinión independiente
python3 herramientas/calibrar_suelo.py --usar-lidar --poses 4 --escribir
```

Mira siempre el `--dibujar`: si las rectas rojas caen sobre la base de los
muros, la calibración vale. Un residuo se puede discutir, una línea que cae dos
centímetros fuera de la pared se ve.

### 5.4 HSV

Rojo y verde vienen de la calibración del equipo (94 % de detección) y **siguen
sin comprobarse en la pista nueva: no había ningún pilar en el campo.**

Azul y naranja **sí están medidos** sobre la lona real (ver 4bis) y se detectan.
Magenta sigue sin calibrar: hace falta el cajón de parqueo a la vista.

### 5.5 Validar y desarmar la traca

```bash
python3 -m legacy.ronda_nueva.ronda_nueva --validar-config
```

`runtime.motion_enabled` viene en `false` y hay cinco calibraciones que se
exigen antes de armar la tracción. Es deliberado.

---

## 6. Desplegar y correr

```bash
bash src/pi5/deploy.sh /home/pi/wro_pi5_$(date +%Y%m%d_%H%M)
cd /home/pi/wro_pi5_...
python3 -m ronda_nueva.ronda_nueva --validar-config
```

Y una corrida, siempre parando con SIGINT (nunca SIGTERM: dejaría el motor
girando a la última consigna):

```bash
timeout -s INT 180 python3 -u -m ronda_nueva.ronda_nueva --arranque-inmediato --sin-parqueo
```

Banderas:

- `--arranque-inmediato` no espera el botón GP21 (para lanzar por SSH).
- `--sin-parqueo` termina al completar las esquinas.
- `--solo-parqueo` entra en la bahía en cuanto hay sentido. **Exige
  `turn_direction` LEFT o RIGHT**: arrancando dentro de la bahía no se cruza
  ninguna línea de sentido y con AUTO no entra nunca.

Los CSV salen en `logs/`. Columnas nuevas que merece la pena mirar:
`segmento`, `avance`, `offset`, `objetivo_offset`, `error_lateral`,
`plan_cedido`, `mapa` (el resumen de las doce casillas, `R0:R.V R1:...`) y
`pilar1_fuente` (`FUSION` / `CAMARA` / `LIDAR` / `ALTURA`).

---

## 7. El parqueo

El detector del hueco es **el mismo que ya funciona**: partir los clústeres en
rectas antes del PCA subió de 0 emparejamientos en 22 barridos a 9 de 10, con
la separación estable en 389–391 mm. Se conserva tal cual.

Lo que cambia es la **maniobra**. La simulación con los radios reales decía que
la de dos arcos se pasa 9 mm sobre un delimitador, y que el techo geométrico de
dos arcos es r ≈ 180 mm —inalcanzable con batalla de 136 mm—. Así que aquí no
se intenta clavar la maniobra de una vez: se entra **en varios tiempos**, como
un coche aparca en línea de verdad, y cada tramo se corta **por medida** (rumbo
alcanzado o holgura mínima), nunca por tiempo. Un vaivén que se queda corto se
corrige en el siguiente en vez de terminar la ronda contra el delimitador.

Además la aproximación usa los **muros magenta que ve la cámara**, que aparecen
mucho antes que los separadores del LiDAR.

---

## 8. Lo que falta, por orden

1. **Poner pilares en el campo y comprobar rojo y verde.** Es lo único que
   queda del bloque de percepción sin verificar, y no se puede hacer sin ellos.
   Con dos postes delante, `herramientas/diag_arranque.py` los lista con su
   color, su posición en milímetros y de qué fuente salió cada una.
2. **Medir con regla la altura de la cámara y el voladizo trasero.** La
   calibración por paredes deja la altura a ±10 mm porque el desplazamiento
   longitudinal no es observable; con la altura medida, `--altura-mm N` cierra
   las dos cosas.
3. **Decidir qué hacer con la deriva del giroscopio.** Ya está compensada por
   software, pero el `except: pass` del firmware puede volver a morder.
4. **Medir `mm_s_per_pwm` en recta y con las ruedas rectas.** El valor 4,0 y la
   tabla del README de la 3B (6,7) discrepan 1,6×. Aquí solo se usa para
   propagar la pose entre barridos, así que el error es menos grave que antes,
   pero conviene cerrarlo.
5. **Primera corrida con motores**, con `--sin-parqueo` y el dedo en el botón.
   Antes hay que poner `runtime.motion_enabled: true` y aprobar las
   calibraciones que falten.
6. **Serie de tres corridas por configuración.** La bitácora del equipo tiene el
   caso de la misma configuración dando 2 y 0 esquinas según 41 mm de colocación
   manual: con una sola corrida no se sabe nada.
7. **Probar `--solo-parqueo`** con el robot dentro de las barreras, ahora que la
   maniobra converge en vez de ser de un solo tiro. Magenta sigue sin calibrar.
8. **Decidir la forma del sector trasero.** Con la máscara medida (140-195), de
   `rear_sector_deg` solo sobreviven 15 grados y todos por la izquierda. La
   ventana honesta son dos lóbulos, `110..140` y `196..230`, y el bloque solo
   admite uno. Solo lo usa `estacionamiento.py`: hay que cerrarlo **antes** de
   estrenar el parqueo, no después.

---

## 9. Pruebas

```bash
cd src/pi5/legacy
python3 -m unittest discover -s ronda_nueva/tests -t . -p "test_*.py"
```

Tarda unos dos minutos: la mayor parte es la vuelta completa simulada, que
genera un barrido LiDAR sintético con oclusión correcta en cada ciclo.

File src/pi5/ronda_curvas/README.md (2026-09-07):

# Ronda de curvas — copia de la Pi 5

Esta carpeta es una copia fiel del código fuente que vive en
`/home/pi/ronda_curvas` en la Raspberry Pi 5. Se conserva sin reescribir su
lógica para poder recuperar y revisar exactamente la versión que usa el robot.

## Contenido

- `ronda_camara.py`: punto de entrada; arranca cámara, LiDAR, Pico y la
  navegación al pulsar el botón GPIO 21.
- `navegacion.py`, `geometria_evasion.py`, `tracker.py` y `sentido_vuelta.py`:
  control de la maniobra de curvas y seguimiento de pilares.
- `camara_driver.py`, `lidar_driver.py`, `lidar_geometria.py`,
  `lidar_mascara.py` y `enlace_pico.py`: acceso a la cámara, RPLIDAR C1 y
  Pico 2.
- `vision.py`, `optica.py`, `geometria_robot.py`, `mapa_oclusion.py` y
  `mapa_pista.py`: percepción, calibración y geometría de apoyo.
- `calib_fov.py`, `calib_hsv.py`, `medir_fov.py`, `medir_modo_2304.py` y
  `sonda_fsm.py`: calibración y diagnóstico.
- `test_pilar.py`, `test_sectores_trasera.py`, `superponer_lidar.py` y
  `ver_pilares.py`, más `tests/`: herramientas y pruebas.

## Qué no se versiona

Se excluyen deliberadamente los artefactos generados por la Pi:

- `logs/*.csv`: telemetría de cada corrida.
- `__pycache__/` y `tests/__pycache__/`: bytecode creado por Python.

## Ejecución y dependencias

Desde esta carpeta, el punto de entrada es:

```bash
python3 ronda_camara.py
```

Debe ejecutarse en la Pi 5 con el hardware conectado. Requiere `RPi.GPIO`,
`picamera2`, `opencv-python`, `numpy` y `pyserial`. Los puertos configurados
en el código son `/dev/ttyUSB0` para el LiDAR y `/dev/ttyACM0` para la Pico.

Antes de usarlo para mover el robot, verifica los puertos, la máscara del
LiDAR y el montaje de cámara. Para el programa modular de Pi 5 consulta
`../ronda_nueva/`; esta carpeta es una copia documentada del programa de la
Pi 5, no un reemplazo de aquel.

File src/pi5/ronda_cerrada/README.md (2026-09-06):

# ronda_cerrada — el cerebro de la 3B, portado a la Pi 5

> **Esto es un PORT.** El contenido a partir de "ronda_nueva" es la bitácora
> original tal y como se escribió en la Raspberry Pi 3B, y se conserva entera
> porque es donde están los porqués. Lo que sigue es solo lo que cambió al
> traerlo, y por qué no se podía copiar tal cual.
>
> Convive con `ronda_nueva/` (el cerebro de mapa de la Pi 5), no lo sustituye.
> Los dos se despliegan juntos y se lanzan por separado:
>
> ```bash
> python3 -m ronda_cerrada.ronda_nueva --validar-config
> python3 -m ronda_nueva.ronda_nueva  --validar-config
> ```

## Qué cambió al portarlo (2026-09-05)

**Origen:** la copia de `src/pi3B/ronda_nueva` del zip del 2 de septiembre.
Ojo: esa copia es anterior a cinco commits de la rama, entre ellos
`34c87bf` *"el sobrepaso sale por geometría, no por cronómetro"*, que es el
arreglo del pilar rojo.

Ningún cambio es cosmético; los cuatro salen de medir este robot.

### 1. La máscara del mástil, remedida

La configuración heredada traía `blind_sectors_deg = [[163, 195]]`, que es del
montaje de la 3B. Medido tres veces en la Pi 5 con
`herramientas/diag_mastil.py`, la estructura fija ocupa **141..212 grados** a
35-68 mm, con eco en el 100 % de los barridos. Pasa a `[[140, 213]]`.

**La máscara es del MONTAJE, no del robot: se remide cada vez que se toca la
cámara.**

### 2. El soporte de la cámara contamina el sector derecho

Hay una segunda estructura fija en **28..54 grados a 142-172 mm**. No va en
`blind_sectors_deg`: ese bloque describe la cuña *trasera* que el compensador
de oclusión sabe proyectar, y `configuracion_desde_mapa` admite **una sola** —
se niega antes que aplicar una geometría que no sabe compensar, y hace bien.

Además los sectores laterales no consultan esa máscara, y el filtro de autoeco
(`self_echo_max_mm` = 150 mm) no cubre un eco a 142-172 mm: lo atraviesa. Sin
tocarlo, la distancia derecha se quedaría clavada en ~142 mm y el centrado
entre paredes dejaría de funcionar.

Se resuelve estrechando el sector: `right_sector_deg` pasa de `[45, 135]` a
`[56, 135]`. Se pierden 11 de 90 grados; el diagnóstico ve 133 puntos de pared
derecha en ese sector, así que sobran.

### 3. Los hombros traseros estaban ciegos al 100 %

`rear_shoulder_offset_deg` era `[18, 35]`, o sea ventanas en 145-162 y 198-215.
Con el mástil en 141..212, **las dos caen enteras dentro de la estructura**: el
robot no podía medir hacia atrás en absoluto. Pasan a `[40, 60]` (ventanas
120-140 y 220-240), que es lo primero que este montaje deja ver.

Tiene un coste que hay que saber: la trasera se obtiene proyectando rayos que
ahora salen a 40-60 grados del eje, no a 18-35. Una pared a 620 mm de rayo son
620·cos(50°) = **399 mm de eje** en vez de los 557 de antes. Es geometría
correcta, pero más sensible a que la pared no esté plana y perpendicular.
**Para el parqueo, el dato bueno de atrás es el ultrasonido**, que este
paquete ya sabe fusionar (`parking.ultrasound_rear_enabled`).

### 4. `turn_direction: AUTO` no funciona en este robot

AUTO resuelve el sentido leyendo la línea de piso con el TCS3472, y en la Pi 5
la Pico responde `COLOR:SIN_SENSOR`: **el sensor no está montado**. Con AUTO la
FSM se quedaría en `WAIT_DIRECTION` hasta agotar `direction_timeout_s`. Pasa a
`RIGHT`; hay que ponerlo a mano según el sentido del sorteo, o engancharlo a la
detección de líneas por cámara que sí tiene `ronda_nueva/vision_pista.py`.

## Lo que NO se ha verificado

- **La extrínseca cámara-LiDAR es la de la 3B** (`forward_from_lidar_mm`
  −99,76 y compañía) y el montaje ha cambiado —el mástil se movió 18 grados—.
  La marca `camera_lidar_extrinsics_ready` viene en `true` heredada, y eso es
  optimista. Degrada la asociación de color con los pilares.
- **Nunca ha rodado con motores en esta placa.** `motion_enabled` sigue en
  `false` y quedan tres calibraciones pendientes, igual que en la 3B.

## Pruebas

145 pruebas offline, todas en verde:

```bash
python -m unittest discover -s src/pi5/ronda_cerrada/tests -t . 
```

Cuatro tuvieron que actualizarse porque fijaban a mano un valor de calibración
del JSON de despliegue en vez de la propiedad que querían comprobar. Es el
mismo error que ya apareció con `parking_side`: una prueba no debe romperse
porque la pista cambie de sentido o el mástil se mueva.

---

# ronda_nueva

Reescritura independiente de la ronda con obstáculos para la Raspberry Pi 3B.
No modifica `ronda_cerrada/` ni `ronda_camara/`: esta última queda como la
referencia funcional del montaje de cámara en mástil.

## Estado honesto

La arquitectura, percepción, fusión, recorrido, estacionamiento y pruebas
offline están implementados, pero **el robot no debe moverse todavía con esta
carpeta**. El JSON entregado conserva `runtime.motion_enabled=false` y tres
calibraciones dinámicas pendientes:

- `vision_ground_support_ready`: falta un frame/video de la cámara de a bordo
  ya instalada para validar ROI, horizonte y soporte de suelo;
- `camera_lidar_timing_ready`: la óptica se midió con el robot quieto; falta
  medir el desfase cámara–LiDAR en movimiento;
- `parking_ready`: faltan radio de giro, signo y posición final medidos en el
  chasis real.

El punto de entrada llama la barrera de configuración antes de importar GPIO o
abrir un puerto. No basta con cambiar `motion_enabled`: todas las calibraciones
del modo solicitado deben estar aprobadas también.

## Qué cambió respecto a `ronda_camara`

| Tema | `ronda_camara` funcional | `ronda_nueva` |
| --- | --- | --- |
| Cámara | un blob HSV, 640×360, sensor completo | varios blobs, 640×360 a 15 FPS, geometría y suelo debajo |
| Óptica | modelo medido en `optica.py` | mismo modo 16:9: HFOV 68,17°, `c0=352,1` y extrínseca en JSON |
| Color | Picamera `RGB888`, array BGR | formato de captura y orden del array son parámetros separados |
| LiDAR trasero | muta `Medicion` con una máscara | resultado explícito con validez y cobertura; `SIN_DATO` no es libre |
| Pilar | tracker único | asociación cámara–LiDAR uno-a-uno y hasta 8 tracks |
| Esquinas | control reactivo + recuperación | giro determinista por sentido, IMU, reapertura y conteo por eventos |
| Final | `abs(yaw)>=1010` | 12 esquinas confirmadas, sin depender de deriva neta de IMU |
| Parqueo | se detiene al reconocer la firma inicial | detecta dos separadores, alinea, hace dos arcos y verifica geometría |
| Watchdogs | LiDAR | LiDAR, cámara, IMU y watchdog autónomo de consignas en la Pico |

Flujo de un ciclo:

```text
Picamera2 -> VisionLigera --timestamp--+
                                        +-> FusionLigera -> tracks --+
RPLIDAR -> ProcesadorLidar ->            |                          |
           PercepcionLidar --------------+--------------------------+-> ControlRuta -> Pico 2
                 |                                                     |
                 +-> paredes / hueco / trasera válida ----------------+
MPU6050 + TCS3472 (Pico) -> heading / color de sentido ----------------+
```

La escritura CSV ocurre en otro hilo y los buffers conservan resultados de
2–4 frames, nunca una cola de imágenes. Las operaciones por barrido son
lineales o sobre un máximo pequeño de tracks; no hay red neuronal, SLAM ni
asignador cúbico.

## Datos ya medidos del chasis nuevo

La carpeta `ronda_camara` midió el montaje el 2026-08-28:

- cámara derecha, sin rotación de 180°;
- Picamera2 solicita `RGB888`, pero el array usado por OpenCV está en BGR;
- modo raw 2304×1296 y salida 640×360 para conservar el sensor completo;
- focal medida 472,9 px, HFOV efectivo 68,17° y centro óptico `cx=352,1`;
- cámara aproximadamente 99,8 mm detrás y 7,0 mm a la derecha del LiDAR;
- el mástil produce eco propio en 165–190°; la máscara usa 163–191°;
- la distancia posterior se recupera con hombros 145–162° y 198–215°.

Las cinco fotos de `ronda_camara/webcam/imagenes` confirman físicamente que el
mástil, soporte y cable plano cruzan el plano trasero del C1. El video externo
`WIN_20260828_21_38_27_Pro.mp4` muestra unas tres vueltas y correcciones en S,
con pasos de poco margen alrededor de 17–19, 37–39, 57–59, 93–95, 107–109 y
163–165 s. Esa grabación es cenital y **no** contiene el feed de la cámara de
a bordo, por lo que no calibra HSV, ROI ni latencia.

## Recorrido y pilares

`ControlRuta` mantiene un único estado activo y da prioridad a la seguridad:

1. fija el sentido por TCS3472 (`AZUL` = izquierda/antihorario, `NARANJA` =
   derecha/horario), o por configuración explícita;
2. centra por rectas laterales robustas y usa el rumbo de pared solo si tiene
   calidad suficiente;
3. entra a una esquina por `frontal_muro`, no por un pilar que tape el frente;
4. cuenta la esquina únicamente tras cambio de heading y reapertura frontal;
5. asocia cada color con un cluster corrigiendo el paralaje de la cámara;
6. para verde pasa por la izquierda y para rojo por la derecha, conserva el
   rumbo durante el sobrepaso y vuelve al centro por posición;
7. una emergencia intenta una reversa corta solo con cobertura trasera real.

El *slew limiter* se aplica a velocidad y dirección, salvo que detenerse sea
urgente. Los límites físicos siguen siendo asimétricos: +25° izquierda y −20°
derecha.

## Estacionamiento

El detector LiDAR busca dos segmentos con la geometría esperada de las paredes
magenta de 200 mm; no intenta inferir su color. Sus centros deben estar a
aproximadamente 353 mm: 333 mm de hueco útil más 20 mm de espesor. La FSM:

```text
SEARCH_GAP -> ALIGN -> ARC_IN -> ARC_OUT -> CENTER -> VERIFY -> DONE
```

Las correcciones geométricas importantes son:

- `ALIGN` coloca el eje trasero, no el LiDAR, respecto al separador;
- el LiDAR está unos 77 mm por delante del centro geométrico del robot, por lo
  que el objetivo centrado es `trasera - frontal = 154 mm`, no cero;
- `frontal + trasera` debe concordar con los 333 mm del hueco;
- la distancia al muro exterior y el paralelismo también deben aprobarse;
- `DONE` necesita tres barridos distintos; un timeout nunca cuenta como éxito;
- un eco de 92 mm o una trasera sin cobertura inhiben toda reversa;
- `ARC_IN` y `ARC_OUT` exigen una distancia lateral real y las dos diagonales
  traseras con cobertura suficiente: un `SIN_DATO` detiene el arco hasta el
  timeout y una holgura crítica termina en `FAILED`, nunca en recuperación.

Los umbrales conservadores están separados en `parking.minimum_*`. Las
coberturas axial y de cada diagonal se guardan también en la telemetría para
que la calibración física no tenga que inferir si un valor grande fue un eco
real o el centinela del C1.

Estos cálculos son verificables offline, pero los arcos aún requieren medir el
radio efectivo del chasis. Por eso `parking_ready` permanece en `false`.

## Pruebas y replay en laptop

Desde la raíz del repositorio:

```bash
python -m compileall -q src/pi3B/ronda_nueva
python -m unittest discover -s src/pi3B/ronda_nueva/tests -v
python -m src.pi3B.ronda_nueva.ronda_nueva --validar-config
```

Replay de imágenes o video. OpenCV decodifica archivos como BGR:

```bash
python -m src.pi3B.ronda_nueva.replay_vision RUTA_A_FRAMES --cada 3
```

Replay sincronizado del formato `captura_*/`:

```bash
python -m src.pi3B.ronda_nueva.replay_captura RUTA_CAPTURA --sentido LEFT
```

Captura estatica en la Raspberry, sin abrir la Pico ni enviar movimiento. La
ruta debe ser nueva; `--solo-camara` tampoco abre ni gira el LiDAR:

```bash
python3 -m ronda_nueva.capturar_calibracion \
  /home/pi/captura_ronda_nueva_YYYYMMDD_HHMMSS --duracion 30
python3 -m ronda_nueva.capturar_calibracion \
  /home/pi/captura_solo_camara_YYYYMMDD_HHMMSS --duracion 5 --solo-camara
```

Para mantener la prueba libre de consignas, `imu.csv` contiene cero sintetico
y `meta.json` lo declara como `synthetic_zero_no_pico`. Sirve para percepcion
estatica y replay en sombra, pero no para aprobar la latencia en movimiento.

El replay estructurado usa únicamente archivos: sincroniza cada barrido con la
última IMU y el último frame que ya existían en ese timestamp, recorre
percepción, fusión, ruta y parqueo en modo sombra y puede exportar las consignas
a CSV. No importa GPIO/Picamera2/serial ni envía comandos a ningún dispositivo.

La captura local de 2026-08-04 pertenece al montaje anterior: sirve para medir
coste y comprobar el reloj relativo, pero debe fallar el diagnóstico del mástil
nuevo. Eso es evidencia de incompatibilidad, no un motivo para relajar la
máscara.

## Despliegue separado

En la Pi, desde un clon del repositorio:

```bash
DESTINO_NUEVO=/home/pi/wro_nueva_20260829
bash src/pi3B/ronda_nueva/deploy.sh --dry-run "$DESTINO_NUEVO"
bash src/pi3B/ronda_nueva/deploy.sh "$DESTINO_NUEVO"
cd "$DESTINO_NUEVO"
python3 -m ronda_nueva.ronda_nueva --validar-config
```

`--dry-run` hace un preflight sin crear archivos. El despliegue real copia
`ronda_nueva/` y `comun/` como paquetes a un staging vecino, comprueba la
sintaxis y solo entonces lo promueve. Si el destino ya existe —incluso vacío o
como enlace— se niega a escribir; para otra versión hay que elegir otro nombre.
No reemplaza el ejecutable funcional ni cambia `controlador_inicio.py`. Cuando
todas las calibraciones estén aprobadas, una prueba de recorrido sin parqueo se
lanza con `--sin-parqueo`; el modo oficial no usa esa opción.

Este despliegue solo prepara la aplicación de la Pi. No flashea ni modifica la
Pico 2; el firmware seguro se instala por separado y debe anunciar `WD:OK` para
que `ronda_nueva` permita armar la tracción.

## Secuencia de validación física pendiente

No realizarla mientras se modifica el chasis.

1. Flashear juntos `src/pico/main.py` y `src/pico/protocolo_seguro.py`; comprobar
   con las ruedas levantadas que al retirar USB la Pico frena y centra en 500 ms.
2. Motores sin armar: capturar 30–60 s de cámara de a bordo y LiDAR, con un
   pilar rojo y uno verde centrados y descentrados.
3. Validar orientación, suelo debajo del blob, FOV y que el diagnóstico de
   163–191° pase varios barridos seguidos.
4. Medir latencia en movimiento lento y ajustar `camera.latency_s`/gate.
5. Habilitar solo recorrido, a velocidad reducida, y revisar el CSV por estado.
6. Medir radio de ambos giros y ejecutar el parqueo con ruedas libres o zona
   despejada antes de probar dentro de los separadores.
7. Solo entonces marcar `parking_ready=true` y `motion_enabled=true` en una
   copia de configuración versionada con la fecha de la medición.

## Sesión de pista 2026-08-31: el radio de giro es el bloqueante

Tres corridas con motores (`--sin-parqueo`, 25 PWM) sobre la pista con los
ocho pilares montados. Los CSV están en el `logs_prueba_*` de cada
despliegue y el video cenital en `video/video-drafts/`.

**Lo que quedó resuelto.** El *fallback* de rumbo funciona: en la corrida
`143903` `RECENTER` terminó por primera vez en «reincorporación
verificada» en vez de agotar su timeout. Las tres corridas mantuvieron
`WD:OK` en el 100 % de los ciclos y la edad de visión se quedó en
67–72 ms de mediana (p95 ≤ 85 ms), así que ni el enlace con la Pico ni la
cámara son cuello de botella.

**La medida que importa.** Con el servo en su tope y 22–23 PWM:

| Magnitud | Valor medido |
| --- | --- |
| Velocidad lineal | 150 mm/s (cierre de `frontal_muro` en recta) |
| Giro máximo a la izquierda | 14,4 °/s |
| Giro máximo a la derecha | 14,1 °/s |
| **Radio de giro mínimo** | **≈ 600 mm, en ambos sentidos** |
| Ángulo de rueda implícito | 12,7° (Ackermann, batalla 136 mm) |

**Esto corrige la hipótesis anterior.** La bitácora del 28-08 atribuía los
fallos a que el robot «no puede hacer las curvas a derechas» por la
asimetría 25°/20° del servo. Los datos dicen otra cosa: izquierda y
derecha giran prácticamente igual (14,4 contra 14,1 °/s, un 2 % de
diferencia). El problema no es la asimetría sino que **ambos lados giran
demasiado poco**: se comandan 20–25° de servo y la rueda solo alcanza
unos 12,7°, es decir, algo más de la mitad del ángulo pedido. La pérdida
está en la relación varilla/horn, no en el firmware ni en el signo.

**Por qué ninguna calibración lo salva.** Un carril WRO mide 1000 mm, así
que una esquina de 90° necesita un radio de unos 400–500 mm. Con 600 mm
el arco no cabe. Se probaron dos calibraciones muy distintas y las dos
fallan por la misma geometría:

- `corner_front_trigger_mm` 650 y `corner_timeout_s` 3,2: el giro se corta
  a los 39° porque el timeout solo da para eso.
- `corner_front_trigger_mm` 900 y `corner_timeout_s` 8,0 (valores que la
  medición justifica): el robot llega a girar 110°, pero `frontal_muro`
  cae de forma monótona de 906 mm a 282 mm y **nunca** vuelve a abrirse a
  los 780 mm que exige la salida. El arco lo lleva contra la pared en vez
  de rodearla; el video cenital muestra al robot cruzando el carril
  entero en lugar de girar dentro de él.

Los valores nuevos (900 mm y 8,0 s) quedan en `configuracion.json` porque
son los que la medición respalda, pero conviene leerlos como «necesarios
y todavía no suficientes».

**Qué desbloquea esto.** Subir el ángulo real de rueda de 12,7° a ~18°
(radio 400 mm) es trabajo mecánico: alargar el brazo del horn del servo o
acortar el del muñón para ganar recorrido, y comprobar que ningún tope
físico esté recortando el giro antes que el firmware. Si el chasis no da
más, la alternativa por software es una maniobra de esquina en tres
tiempos (avanzar girando, retroceder al contrario, avanzar), que el
reglamento no prohíbe pero cuesta segundos de ronda. Conviene medir el
ángulo de rueda con un transportador antes de decidir.

## Cierre real de la sesión: tres corridas seguidas sin fallo terminal

| Corrida | Esquinas | Emerg. | Sueltas | Fin |
| --- | --- | --- | --- | --- |
| 18:22 (soltar pilar) | 5 | 0 | 0 | **no falló** |
| 18:39 (desde la curva) | 4 | 39 | 0 | **no falló** |
| 18:46 (herencia de color) | 4 | 22 | 1 | **no falló** |

Antes de estos dos arreglos, **dos de cada tres corridas morían por
timeout a los 46-50 s**. Ahora ninguna de las tres muere: las tres llegan
al final de la ventana de prueba. El techo bajó de 6 a 4-5 esquinas, pero
el suelo subió, que era exactamente lo que se buscaba.

Dos comprobaciones directas de que los arreglos actúan:

- En la corrida `184623` se ve el ciclo completo en el CSV: a los 39,7 s
  «track bloqueado perdido; parada para reasociar» y a los 40,5 s «pilar
  no reasociado; se suelta y sigue el carril». **0,8 s de espera en vez de
  los 9,7 s** que antes acababan en `FAILED`.
- La última observación directa de un track llegó a **y = 8 mm**, contra
  los 63-70 mm típicos de antes: la herencia de color mantiene el pilar
  identificado hasta pegado al morro.

Lo que sigue abierto es un caso distinto del punto ciego: **tracks que se
pierden lejos**, a 470 y 774 mm en esta misma corrida. Algunos coinciden
con giros fuertes (13-15°/s) pero otros no, así que la hipótesis del error
de predicción durante el giro no los explica todos. Hace falta
instrumentar la fusión para verlo; los CSV de control no bastan.

## Estado al cierre de la sesión del 2026-08-31

Mejor corrida: **6 esquinas, 6 pilares rebasados, cero emergencias**, 86,7 s
hasta que la cortó el timeout externo de la prueba (`161726`). Es media
ronda —12 esquinas son las tres vueltas— con las cuatro reincorporaciones
verificadas y ningún `RECOVERY`.

| | inicio de sesión | cierre |
| --- | --- | --- |
| Esquinas | 0 | **6** |
| Emergencias | 8–196 | **0** |
| Duración antes de fallar | 14 s | 86,7 s (sin fallar) |

Ritmo medido: 13,8 s por esquina, que extrapolado a las doce da **164 s**
contra el límite de 180. Cabe, pero con poco margen: cualquier maniobra de
tres tiempos o recuperación extra se lo come. Ese margen es lo que
compraría bajar el radio de giro.

Aviso de método, que esta misma sesión demostró: **es una sola corrida**.
La repetición de una configuración dio 2 y 0 esquinas por 41 mm de
colocación inicial (más abajo). Antes de dar por buena cualquier cifra
hacen falta tres corridas.

## Por qué la visión sale a 640×360 y no al tamaño del sensor

Pregunta recurrente, medida el 2026-08-31 en la propia Pi 3B con un frame
real de a bordo y el pipeline completo (`VisionLigera.procesar`):

| Modo | ms/frame | fps máximo | coste | pilares detectados |
| --- | --- | --- | --- | --- |
| **640×360** | **34,0** | 29,4 | 1,0× | 2 |
| 1280×720 | 129,5 | 7,7 | 3,8× | 2 |
| 2304×1296 | 405,1 | 2,5 | 11,9× | 2 |

El presupuesto a 15 fps es de 66,7 ms por frame, y ese presupuesto se
comparte con el LiDAR, la fusión y el control. A 640×360 el pipeline usa
la mitad y sobra margen; a 2304×1296 tarda **seis veces** más de lo que
hay, y el ritmo real caería a 2,5 fps. La edad de visión pasaría de los
~70 ms medidos a más de 400: a 150 mm/s eso son 60 mm de desplazamiento
entre frames en vez de 10, con el control ciego entre medias.

Y no se gana nada a cambio: **detecta los mismos dos pilares en las tres
resoluciones**.

Conviene entender por qué no se está perdiendo campo de visión. El sensor
**ya lee a 2304×1296** (`raw_sensor_size`), que es el fotograma completo;
ese modo se eligió el 28-08 justamente para no recortar. El reescalado a
640×360 lo hace el ISP del chip por hardware, sin coste de CPU, y además
promedia píxeles, lo que reduce ruido. Lo único que cambiaría subiendo la
salida es cuántos píxeles recorre OpenCV en la CPU.

Dicho de otro modo: el campo de visión ya es el máximo, y el punto ciego
cercano de la sección siguiente es **geométrico**, no de resolución — con
cuatro veces más píxeles la base del pilar seguiría cayendo exactamente
igual fuera del encuadre.

## Punto ciego a corta distancia: el LiDAR ve y la cámara no

El atasco de la cuarta esquina (corrida `154741`, segundo 67) es un bucle
`TURN` → `RECOVERY` → `CRUISE` → `TURN` repetido cuatro veces. El CSV lo
explica con dos columnas:

- en `TURN`, `frontal == frontal_muro` (596 = 596): lo más cercano es la
  pared;
- en `RECOVERY`, `frontal = 116` pero `frontal_muro = 597`: **hay un
  objeto a 12 cm que no es pared**;
- y a la vez `tracks = 3`, `tracks_confirmados = 0`.

O sea: el robot tiene un pilar pegado al morro, el LiDAR lo ve, y **no
sabe de qué color es**. Sin color no hay regla de evasión que aplicar, así
que el pilar solo existe como disparador de emergencia. `TURN` gira, el
pilar entra en el sector frontal, salta la emergencia, `RECOVERY`
retrocede, el pilar sale, y vuelta a empezar.

### Dónde empieza el punto ciego

Medido sobre un frame real de a bordo (captura `pilar_verde_160314`,
robot quieto, sin abrir la Pico), usando la óptica ya calibrada
(f = 472,9 px) y los dos pilares del encuadre como referencias:

| Pilar | Alto aparente | Distancia al LiDAR | Base en el frame |
| --- | --- | --- | --- |
| verde | 125 px | **657 mm** | 0,556 |
| rojo | 67 px | 1312 mm | 0,410 |

Los 657 mm calculados coinciden con los ~60 cm medidos a mano, lo que
confirma de paso que la óptica está bien. Ajustando `y = 0,241 + 237,8/d`
y despejando en el recorte inferior de la ROI (`roi_bottom_ratio` 0,92):

> **La base del pilar sale del encuadre a unos 251 mm del LiDAR.**

Por debajo de esa distancia no hay suelo bajo el blob, y `min_ground_support`
—la comprobación que se adoptó del campeón 2025 para descartar falsos
positivos— lo rechaza. La comprobación es correcta; simplemente nadie
había medido a partir de qué distancia empieza a rechazar pilares buenos.

A 657 mm la detección es sólida: el replay en sombra confirmó el color en
63 de 64 barridos.

### La incoherencia que esto destapa

`obstacle_pass_y_mm` vale 160 mm: el robot considera que «ya está
rebasando» el pilar cuando lo tiene a 16 cm. Pero **lo pierde de vista a
25 cm**. Hay una franja de 9 cm en la que la maniobra depende de un color
que ya no se está midiendo.

Dos arreglos, complementarios:

1. **Subir el umbral de sobrepaso por encima del punto ciego** (~260 mm),
   para congelar el rumbo mientras el dato todavía es válido en vez de
   perseguir un punto de paso con información que ya no existe. Es
   calibración, no código.
2. **Conservar el color del track cuando el LiDAR lo sigue viendo pero la
   cámara ya no.** La fusión ya acumula votos por track; falta que el
   track no se dé por perdido y se recree en blanco al entrar en la zona
   ciega. El lado de paso se seguiría recalculando con la posición actual,
   no congelado.

## La causa raíz: el punto de paso no cabía en el hueco

Todo lo que sigue en esta bitácora —la guardia de pared secuestrando el
mando, el robot llegando en diagonal a la esquina, la falta de
repetibilidad— sale de un solo parámetro mal calibrado.

El tramo inferior deja **333 mm de la pared al centro del pilar verde**,
medido por el LiDAR (la suma `izquierda + track_activo_x` converge a ese
valor en dos corridas independientes). Descontando el medio pilar quedan
308 mm libres para un robot de 125 mm de ancho.

`obstacle_lateral_clearance_mm` estaba en **255 mm**, que pide 76 mm más
de los que existen:

| Con 255 mm | Con 179 mm |
| --- | --- |
| punto de paso a 78 mm de la pared | a 154 mm |
| borde del robot a **16 mm** — no cabe | a 92 mm, centrado en el hueco |

El robot nunca llegaba a ese punto imposible: la guardia de pared lo
frenaba antes de tocar. **La guardia llevaba toda la sesión compensando
un objetivo que no existía**, y ese rescate era justo lo que lo empujaba
de vuelta hacia el pilar. Eso explica también por qué quitarle el término
lateral (más abajo) salió tan mal: se quitó el parche sin arreglar la
causa que lo hacía necesario.

### Resultado en pista

| | clearance 255 | clearance 255 (rep.) | **clearance 179** |
| --- | --- | --- | --- |
| Paso junto al pilar | 130 mm | 147 mm | **234 mm** |
| Esquinas | 2 | 0 | **3** |
| Fin | timeout | timeout | **no falló** |

La corrida con 179 mm corrió **71,5 s sin fallar**, hasta que la cortó el
timeout externo de la prueba; las anteriores morían entre 14 y 45 s. Las
dos reincorporaciones se verificaron y las tres esquinas se cerraron.

Y hay un efecto de segundo orden que conviene notar: pasando a 234 mm de
la pared, por encima de `wall_guard_start_mm` (230), **la guardia ya no
llega a activarse durante la evasión**. El lado de paso vuelve a decidirlo
el color por sí solo, sin necesidad de tocar la lógica de la guardia.
Arreglada la causa, el síntoma desaparece.

Queda abierto el atasco de la cuarta esquina, hacia el segundo 67: entra
en un ciclo `TURN` → `RECOVERY` del que no sale. Ese caso todavía no
tiene diagnóstico.

## El lado de paso lo decide el color, no la pared

Diagnóstico del equipo durante la sesión, confirmado después con los CSV:
el lado por el que se rebasa un pilar lo acababa decidiendo el LiDAR.

`_con_guardia_pared` mezcla el ángulo de la evasión con un «protector» de
pared cuyo peso crece al acercarse. En la corrida `145857` ese peso llegó
a **0,94**: el robot iba a −18°, girando *hacia* el pilar que estaba
esquivando, mientras la pared izquierda se le acercaba a 131 mm.

No era un caso extremo sino la regla. La geometría lo obliga:

| | |
| --- | --- |
| Carril | 1000 mm |
| Pilar | 50 mm |
| Robot | 125 mm |
| **Margen a la pared al rebasar** | **≈175 mm** |
| `wall_guard_start_mm` | 230 mm |

Rebasar un pilar deja siempre menos margen del que dispara la guardia, así
que ésta intervenía en **toda** evasión normal, no como excepción.

La causa concreta es el término lateral del protector, que devuelve el
robot al centro del carril; durante una evasión ese centro está al otro
lado del pilar. Ahora, mientras hay un pilar activo y la holgura no es
crítica, el protector conserva **solo el término de rumbo**: la pared
corrige la orientación para no chocar, pero no reabre una decisión que es
del color. Por debajo de `wall_guard_full_mm` recupera toda su autoridad,
porque ahí manda no chocar.

Bajar el umbral de la guardia (230 → 165) se probó primero y **no es la
solución**: cierra las esquinas pero el robot pasa a rozar la pared a
111 mm, a 21 mm de la emergencia lateral.

**La pista refutó el cambio y se revirtió.** Repetido desde la línea de
salida, dejar solo el término de rumbo dio **cero esquinas** frente a las
dos de la mejor configuración: sin el término lateral el robot llega al
recentrado pegado a la pared y agota su timeout antes de la primera
esquina. Ese término es también lo que impide pegarse, así que se
conserva; el desvío hay que corregirlo antes, en el punto de paso, no
quitándole autoridad a la pared. Bajar el umbral (230 → 165) tampoco
sirve: cierra esquinas pero roza a 111 mm, a 21 mm de la emergencia.

Queda un test que fija el término lateral en su sitio, para que el
intento no se repita sin leer antes esta bitácora.

### Lo que sí resolvió el caso

Persiguiendo esto apareció la causa real de los timeouts de
reincorporación: **el criterio de «centrado» exigía calidad de ajuste de
pared**. Tras rebasar un pilar esa calidad cae (0,21 medido), y el robot
se quedaba centrado —108 mm de error, dentro de la tolerancia de 150— sin
poder confirmarlo nunca. Estar centrado es una afirmación sobre
distancias medidas, no sobre lo bien que se ajustó una recta; la calidad
sigue gobernando el mando en `_angulo_pared`, que es donde importa.

| Configuración (desde la misma salida) | Esquinas | Margen | Emerg. |
| --- | --- | --- | --- |
| handoff 900, guardia 230/125 | 1 | 131 mm | 0 |
| handoff 700, guardia 165/110 | 2 | 111 mm | 8 |
| handoff 700, guardia solo-rumbo | 0 | 127 mm | 0 |
| handoff 700, guardia 230/125 | 0 | 138 mm | 0 |
| handoff 700, 230/125 + centrado por laterales | 2 | 130 mm | 0 |
| **la misma, repetida sin tocar nada** | **0** | **103 mm** | **90** |

## El resultado no es repetible, y eso manda sobre la tabla

La última fila es la medición más importante de la sesión. Es la **misma
configuración, desde la misma salida, sin cambiar una sola línea**, y da
el resultado opuesto: cero esquinas y noventa ciclos de emergencia frente
a dos esquinas y ninguna.

Lo único que difiere es la colocación manual de partida:

| | corrida A | corrida B |
| --- | --- | --- |
| izquierda | 449,7 mm | 408,1 mm |
| derecha | 530,9 mm | 570,7 mm |
| Resultado | 2 esquinas | 0 esquinas |

**41 mm de desplazamiento lateral inicial** —un 4 % del carril— deciden si
la vuelta progresa o se atasca. Y el margen a la pared tampoco explica
nada: la corrida con **menos** margen (111 mm) cerró dos esquinas y una
con **más** (138 mm) no cerró ninguna.

La conclusión es incómoda pero clara: con un radio de giro de 600 mm en
un carril de 1000, el sistema corre pegado al límite de su envolvente
física, y ahí la varianza domina sobre cualquier ajuste de parámetros.
Seguir afinando umbrales es perseguir ruido. **La siguiente mejora real
es mecánica** —subir el ángulo de rueda de 12,7° a ~18°— y hasta que
llegue, cualquier tabla comparativa de configuraciones que se mida con
una sola corrida por fila estará midiendo azar.

Nota de método: en una versión anterior de esta tabla el margen de la
quinta fila se anotó como 214 mm. Era un error de lectura —ese valor era
la distancia lateral en un instante concreto, no el mínimo del tramo—; el
mínimo real es 130 mm y todas las filas se recalcularon con el mismo
criterio.

## Maniobra de esquina en tres tiempos

Puente por software mientras el chasis no gane ángulo de rueda. Vive
dentro del estado `TURN` (sin estados nuevos en la FSM) y se apaga con
`corner_kturn_enabled`, que es lo que convendrá hacer si el radio baja a
400 mm.

El detalle que la hace funcionar es el signo del volante: con Ackermann
la rotación es `omega = v*tan(delta)/L`, así que **al retroceder el
volante va al lado contrario** para que el morro siga rotando hacia el
mismo lado. Usar el mismo ángulo que en avance desharía el giro. Hay una
prueba que fija ese signo en los dos sentidos de vuelta.

La reversa exige lo mismo que la recuperación: trasera válida y con
holgura. Un `SIN_DATO` detiene la maniobra en vez de ejecutarla a ciegas,
porque el mástil ya ciega ese arco.

### Lo que enseñó la pista

| Corrida | Esquinas | Conmutaciones | Ciclos en reversa | Fin |
| --- | --- | --- | --- | --- |
| `145409` (primera versión) | 2 | 12 | 38 | timeout de recuperación |
| `145857` (con histéresis) | 1 | 2 | 39 | timeout completando esquina |

La primera prueba cerró dos esquinas, pero los tramos 2 al 6 fueron
oscilación pura: conmutaba cada 0,2 s y el robot no llegaba a desplazarse
porque el *slew* de velocidad nunca alcanzaba el PWM pedido. **La causa no
era ruido del sensor**: en la esquina el sector trasero cruza la arista
entre dos paredes y la lectura alterna entre dos valores reales, 258 y
690 mm, los dos con `trasera_valida` y cobertura sobre 0,97. El umbral de
confort de 300 mm caía justo entre ambos modos.

Ahora un tramo empezado solo lo corta el límite duro
(`emergency_rear_mm`, que 258 mm no viola) o su duración mínima; la
holgura de confort decide únicamente si un tramo **nuevo** puede empezar.
Con eso las conmutaciones bajan de 12 a 2 y el tramo útil pasa de rebotes
de 0,2 s a uno continuo de 3,9 s.

### Lo que sigue abierto

La esquina 1 se cierra de una sola pasada en las dos corridas, sin
necesitar la maniobra. La que falla es la **segunda**, y por una causa
distinta del radio: el pilar de esa esquina deja al robot descolocado y
`RECENTER` cede el mando a `TURN` 0,1 s después de entrar, con
`recenter_corner_handoff_mm` en 900 mm. Llega en diagonal y termina
encajonado con unos 250 mm por delante y 240 mm por detrás: ahí ya no
cabe ninguna maniobra. Bajar el *handoff* para que se reincorpore antes
de girar choca con haber subido el disparo de esquina a 900 mm por el
radio; las dos cosas no se pueden tener a la vez con este chasis.

El `corner_timeout_s` de 14 s tampoco es viable en competencia: doce
esquinas no caben en los 3 minutos de ronda. La maniobra sirve para
seguir probando el resto del recorrido, no como configuración de
carrera.

## Watchdog autónomo de la Pico

`src/pico/main.py` usa ahora `src/pico/protocolo_seguro.py`: solo acepta tramas
acotadas y, si pasan 500 ms sin una consigna válida, frena, centra el servo y
publica `WD:STOP`. La aplicación exige observar `WD:OK` antes de armar y durante
la carrera, conservando compatible el parser histórico de IMU/color.

El 2026-08-29 se cargó el firmware en la Pico real y se verificaron los hashes:
con heartbeat `0,0` anunció `WD:OK` y, al dejar de transmitir sin desconectar el
cable, volvió a `WD:STOP` en 465 ms. No se envió velocidad distinta de cero.
Todavía falta la comprobación complementaria desconectando físicamente el USB
con las ruedas levantadas. Copiar `ronda_nueva` a la Raspberry no actualiza
automáticamente el firmware que ya esté en la Pico.

Las fuentes internacionales estudiadas y las decisiones de portabilidad están
en [`REFERENCIAS_2025.md`](REFERENCIAS_2025.md).

## El sentido detectado NO es el que llevábamos configurado

Primera corrida real en `AUTO` (`185856`). El robot avanzó **11,6 s
buscando la línea**, centrado por las paredes, y al cruzarla fijó el
sentido:

| | |
| --- | --- |
| Primer color de línea leído | **AZUL** a los 11,58 s |
| Sentido fijado | **ANTIHORARIO (LEFT)** |
| Giro ejecutado | +25° de servo, heading −4,8° → +67,3° |

Todas las corridas del día se hicieron con `RIGHT` escrito a mano. Si la
lectura es correcta, **íbamos en el sentido contrario al que marca la
pista**, y eso invalida como referencia buena parte de lo medido hoy en
esquinas.

Hay un segundo efecto, y no es menor. Los topes de dirección son
asimétricos —+25° a la izquierda contra −20° a la derecha— así que el
sentido cambia el radio de giro:

| Sentido de giro | Velocidad angular | Radio implicado |
| --- | --- | --- |
| Izquierda (+25°) | 15,4 °/s | **559 mm** |
| Derecha (−20°) | 13,9 °/s | 617 mm |

Girando a la izquierda el robot cierra **58 mm más de radio**. Es la
misma diferencia que llevamos todo el día intentando ganar por software.
Ojo: la cifra de la izquierda sale de **una sola esquina**, así que hay
que repetirla antes de darla por buena.

Queda por confirmar que la convención `AZUL → LEFT` es la correcta para
esta pista; si estuviera invertida se corrige en `floor_color_left` y
`floor_color_right` sin tocar código. Y los 11,6 s de búsqueda son
demasiados: el timeout está en 12, así que faltó poco para fallar, y en
competencia son 11,6 s de los 180 gastados antes de empezar.

## El sentido detectado depende de la pose de arranque, no de la pista

Cinco corridas en `AUTO`, y el patrón no admite dudas:

| Pose de arranque | 1.ª línea | Sentido fijado | Esquinas |
| --- | --- | --- | --- |
| Recta inferior (×4) | AZUL | ANTIHORARIO | **1, 1, 1, 1** |
| Carril izquierdo | NARANJA | HORARIO | **3** |

La detección **funciona y es repetible**: cuatro veces seguidas leyó lo
mismo desde la misma pose. Y en el carril izquierdo el vídeo confirma que
el robot avanzaba hacia arriba, que es sentido horario — exactamente lo
que dedujo de la línea naranja. Sensor y realidad coinciden.

Lo que esto destapa es conceptual: **el robot no detecta el sentido de la
pista, detecta el sentido en el que lo han colocado**. Cruzar primero azul
o naranja depende de hacia dónde apunta al arrancar. Si la orientación
física y el sentido deducido no concuerdan, el robot gira hacia el lado
contrario del que avanza y se mete contra el bloque o la pared.

Esa es la explicación más probable de los cuatro fallos desde la recta
inferior: allí se colocó siempre con la orientación que veníamos usando
para recorrer en horario, pero la línea que cruzaba le decía antihorario.

**Prueba pendiente que lo resolvería:** colocar el robot en la recta
inferior apuntando al lado contrario del habitual, de modo que su marcha
física sea antihoraria. Si entonces lee AZUL y completa varias esquinas,
queda confirmado que el problema era la incoherencia entre pose y sentido,
no la detección ni el control.

## El eco de la dirección era el bloqueante del sentido antihorario

Corriendo en el sentido correcto (antihorario), el robot moría siempre en
la primera esquina. La causa no era el sentido: **al girar, la rueda entra
en el barrido lateral del LiDAR**.

El perímetro está a 61 mm por la izquierda y 45 por la derecha del eje del
LiDAR, así que cualquier lectura por debajo de eso es físicamente
imposible. Contando sobre todas las corridas del 31-08 y el 01-09:

| Lado | Lecturas imposibles | Ángulo mediano del servo |
| --- | --- | --- |
| Izquierda (<80 mm) | 101 | **+17,3°** (girando a la izquierda) |
| Derecha (<65 mm) | 90 | **−8,0°** (girando a la derecha) |

La correlación entre el lado imposible y el lado hacia el que gira el
servo no deja mucho margen de duda. `wall_side_min_mm` ya protegía el
ajuste de rectas, pero cuando no hay recta el lateral cae al mínimo crudo
del sector, que no pasa por ese filtro. En la corrida `124629` la lateral
izquierda marcó 51, 50 y 49 mm en tres `RECOVERY` seguidos, con el robot
girando y sin nada a su lado.

Resultado de descartar como sin dato cualquier eco más cercano que el
propio chasis, en el sentido antihorario:

| Corrida | Esquinas | Duración | Emergencias | Lecturas imposibles |
| --- | --- | --- | --- | --- |
| 18:58 – 12:46 (seis corridas) | 0–1 | 21–46 s | 30–153 | 0–58 |
| **12:52 (con filtro)** | **5** | **143,7 s** | **42** | **0** |

De una esquina a cinco, y de morir a los 40 s a llegar a 144. Once pilares
rebasados por el camino.

**Lo que limita ahora es el ritmo, no los atascos:** 24 s por esquina, que
a doce esquinas son 288 s contra los 180 de una ronda. El tiempo se va en
las evasiones, no en las esquinas, y la velocidad configurada para las
pruebas es de 25 PWM (unos 100 mm/s). Subirla es el siguiente paso, ya en
terreno de afinado y no de depuración.

## Intento de subir la velocidad: fallido, revertido

Con el eco lateral filtrado, el límite pasó a ser el ritmo: 24 s por
esquina son 288 s a doce, contra los 180 de una ronda. Subir el crucero de
25 a 35 PWM no funcionó, y el porqué es instructivo.

**La velocidad no rompió nada nuevo, hizo insostenible algo que ya estaba
justo.** El sector frontal pasaba de 760 a 30 mm en un solo barrido de
0,1 s, cuando a esa velocidad el robot avanza 12: el pilar que hay tras la
esquina no se acercaba, aparecía. Está fuera del campo durante todo el
giro. A 25 PWM había margen de reacción; a 35 la emergencia llegaba con el
pilar tocando el morro.

Se probaron dos arreglos y **ninguno sirvió**:

- *Salida lenta de esquina* (1,5 s a velocidad de evasión tras cada giro).
  No bastó: el siguiente fallo fue lateral, con el eco de la rueda a
  91-107 mm, por encima del umbral de 80 que lo filtraba.
- *Filtro de continuidad lateral*, rechazando saltos físicamente
  imposibles (832 → 101 mm en un barrido). Descartaba la lateral derecha
  desde el primer ciclo y la corrida moría a los 12 s. **Revertido.**

Subir el umbral del fallback de 80 a 160 mm tampoco ayudó: con esa
configuración la corrida hizo las mismas cinco esquinas pero con **136
emergencias frente a 42**, y 30 s por esquina en vez de 24.

La configuración volvió a la de la corrida `125223`, que sigue siendo la
mejor medida: crucero 25 PWM, `lateral_fallback_min_mm` 80, sin salida
lenta de esquina.

**Lo que esto enseña sobre el orden de trabajo:** el pilar oculto tras la
esquina hay que resolverlo *antes* de tocar la velocidad, no después. Y
mientras el eco de la rueda no se distinga de una pared por algo mejor que
un umbral de distancia —lo natural sería enmascarar el sector en función
del ángulo del servo, que el robot conoce— cada subida de velocidad va a
volver a chocar con él.

## Serie de cinco: la primera medida que merece ese nombre

Cinco corridas seguidas, misma configuracion, sin tocar nada entre ellas.
Es lo que faltaba en todo lo anterior, donde cada decision se tomaba sobre
una sola corrida.

| Run | Esquinas | Vueltas | Duración | Emerg. | Fin |
| --- | --- | --- | --- | --- | --- |
| 1 | 7 | 1,8 | 171,6 s | 11 | no falló |
| 2 | 6 | 1,5 | 171,8 s | 172 | no falló |
| 3 | **8** | **2,0** | 176,9 s | 86 | no falló |
| 4 | 4 | 1,0 | 81,7 s | 0 | timeout reincorporación |
| 5 | 6 | 1,5 | 106,5 s | 69 | timeout recuperación |

**Mediana 6 esquinas (vuelta y media), rango 4-8. Tres de cinco llegan al
final de la ventana de 180 s.** Esa es la linea base real, y hay que
compararla con lo que veniamos creyendo: la corrida de 5 esquinas que
tomamos por «la mejor» y la de 1 esquina que nos hizo revertir estaban
las dos dentro de este mismo rango. Ninguna de las dos medía el codigo.

Dos observaciones que solo aparecen con la serie:

- **Las emergencias no predicen el resultado.** La run 1 hizo 7 esquinas
  con 11 y la run 2 hizo 6 con 172. La run 4, con **cero** emergencias,
  es la peor de todas. Como metrica de calidad no sirve; solo cuentan las
  esquinas y la duración.
- **Los dos fallos son de recentrado y recuperación**, no de percepción ni
  de esquina. Ahi esta el trabajo que queda.

Para las tres vueltas faltan 6 esquinas sobre la mediana, y el ritmo de
~21 s por esquina las situa en 250-270 s contra los 180 del limite. No es
cuestion de estabilidad: hace falta velocidad, y subirla choca con el
pilar que aparece tras la esquina.

## Latencia del LiDAR, ultrasonido trasero y parqueo modular

Tres cambios que van juntos porque los tres atacan lo mismo: el control
estaba decidiendo con informacion que ya no describia la pista.

### El retraso del LiDAR era de adquisicion, no de proceso

`comun/lidar_driver.py` leia el puerto **byte a byte**: un `read(1)` para el
byte de cabecera y un `read(4)` para el resto, por cada muestra. A 460800
bps el C1 entrega ~9200 paquetes/s, o sea **~18400 llamadas de sistema por
segundo** solo para recibir. Y el callback del hilo de lectura era el ciclo
de decision completo (geometria, fusion, vision, control, metricas): 15-30
ms en los que el kernel seguia acumulando bytes. Al volver a leer, el driver
procesaba paquetes viejos, y el retraso **crecia solo**, porque cada barrido
atrasado tardaba lo mismo en procesarse que uno fresco.

Lo que se hizo:

- **Lectura en bloques.** Cada vuelta del hilo drena con una sola llamada
  todo lo pendiente (`read(in_waiting)`) y decodifica el lote entero de una
  vez, vectorizado con numpy (hay una rama pura equivalente si numpy falta).
  El `read(1)` bloqueante se conserva solo como espera pasiva cuando el
  LiDAR calla, para no quemar CPU girando en vacio.
- **Sincronizacion explicita.** El parser exige una racha de 12 paquetes
  coherentes antes de fiarse de una alineacion; los dos check bits del
  protocolo dejan pasar 1 de cada 4 posiciones al azar, asi que un solo
  paquete no basta. Ante un byte corrupto se resincroniza y cuenta el
  episodio (`driver.resincronizaciones`).
- **Filtro de angulo imposible.** El campo trae 15 bits, hasta 511,98
  grados. Un paquete corrupto que superara los check bits terminaba aliasado
  dentro de `construir_perfil_360` (`indice % 360`) inventando un obstaculo
  en un sector que nadie miraba. Ahora se descarta.
- **Buzon de un solo hueco.** `BuzonBarridosLidar` no es una cola: el
  barrido nuevo pisa al que no llego a consumirse. Encolar habria sido peor
  que descartar, porque el robot acabaria esquivando donde el pilar *estaba*.
- **El bucle principal es el bucle de control.** El hilo del LiDAR solo
  publica; el ciclo de decision corre en el hilo principal, que ya hacia los
  watchdogs. Perception, fusion y FSM usan el **timestamp de captura**, no el
  de proceso: eso ademas alinea de verdad la fusion con la camara, que
  siempre uso su instante de captura.

Los watchdogs siguen midiendo contra la hora real (`time.monotonic()`), no
contra la del dato: usarla los haria mas indulgentes justo cuanto mas
atrasado fuera el sistema.

Dos columnas nuevas en el CSV para comprobarlo en pista:

- `lidar_edad_ms`: edad del barrido en el instante de emitir la consigna.
  **Tiene que quedarse plana, no crecer.** Si sube monotonamente durante la
  corrida, el buffer se esta volviendo a acumular.
- `barridos_descartados`: cuantas veces un barrido quedo obsoleto sin
  consumirse. Un numero pequeno y estable es normal; uno que crece rapido
  dice que el ciclo de decision no llega a 10 Hz.

### Ultrasonido trasero (HC-SR04 / US-100)

**Cableado: Trigger en GP14, Echo en GP15.** Son los pines libres mas
comodos: GP12 es el servo, GP16-GP19 los dos buses I2C, GP22 el PWM del
motor y GP26-GP28 el TB6612FNG.

> **Aviso.** El Echo del HC-SR04 sale a 5 V y los GPIO de la Pico **no**
> toleran 5 V. Hay que bajarlo con un divisor (1 k en serie desde Echo, 2 k
> a GND) o usar un US-100 alimentado a 3,3 V. Sin eso se dana la entrada.

El firmware **no** usa `machine.time_pulse_us`: esa llamada bloquea hasta 30
ms esperando el eco, y el bucle de la Pico corre cada 5 ms sosteniendo el
servo, el motor y el watchdog de comandos. En su lugar se lanza el pulso
(10 us de bloqueo) y se cronometra el flanco por **interrupcion**, de modo
que el control sigue corriendo mientras el sonido viaja. Periodo de disparo:
60 ms, que es lo que el HC-SR04 pide para no arrastrar ecos fantasma.

La conversion y el filtrado viven en `src/pico/ultrasonido.py`, sin importar
`machine`, para poder probarlos en CPython igual que `protocolo_seguro.py`.
El filtro publica la **mediana de tres** muestras y caduca la medida tras
tres intentos sin eco: lo peor que puede hacer un sensor de distancia es
seguir publicando la ultima lectura buena cuando ya no ve nada.

> **Al desplegar hay que copiar `ultrasonido.py` a la Pico junto a
> `main.py`.** Si falta, el firmware arranca igual y manda `US:-1`; no se
> cae, pero tampoco hay sensor.

Trama de telemetria: `IMU:...,COLOR:...,US:185,WD:OK`. El campo va antes de
`WD` y los parsers recorren campos por nombre, asi que el firmware anterior
y `comun/enlace_pico.py` (que corta por la primera coma) siguen funcionando.
`US:-1` significa *sin medida*, nunca *libre*.

### Parqueo: una sola entrada y trasera fusionada

`ejecutar_estacionamiento(controlador, hueco, heading, medidas, ahora)` es
ahora el unico punto de entrada. Las medidas viajan en un `MedidasParqueo`
en vez de una docena de argumentos sueltos, y la tolerancia a que la FSM
cambie de firma se movio de `control_ruta` a `estacionamiento.py`, junto a
la FSM que la necesita.

**Regla de fusion de la trasera: se toma la MENOR de las dos fuentes.** El
razonamiento es asimetrico a proposito. Los dos modos de fallo conocidos del
LiDAR aqui —el sector ciego del mastil (163-195 grados) y el eco de la
propia rueda— hacen que informe de *mas* espacio del que hay, o de ninguno;
nunca de menos. Quedarse con la menor significa que:

- el ultrasonido manda justo cuando ve algo que el LiDAR no vio, que es para
  lo que se monto;
- nunca puede autorizar una reversa que el LiDAR ya considera peligrosa.

Con el robot en angulo dentro del arco, el sensor puede estar midiendo el
separador y no la pared del fondo. Sigue siendo el numero seguro, y la
comprobacion de que `frontal + trasera` equivale al largo del hueco impide
cerrar el centrado con esa medida.

Lo que el ultrasonido **no** sustituye: las diagonales traseras. Mira recto
hacia atras y no ve las esquinas, asi que esas siguen saliendo del LiDAR y
su ausencia sigue frenando el arco. La comprobacion de cobertura, que es una
metrica del LiDAR, se omite solo cuando el numero lo puso el ultrasonido.

#### Como probar el parqueo aislado: `--solo-parqueo`

El unico acceso normal al estacionamiento esta **despues de verificar una
esquina** (`_procesar_giro`, justo tras incrementar el contador). Como
completar una esquina es precisamente lo que bloquea el radio de giro, sin
una puerta directa la FSM de parqueo no se puede ejercitar en pista.

`--solo-parqueo` pone `corners_before_parking` a 0, y con ese valor la FSM
entra a buscar la bahia en cuanto conoce el sentido de carrera. Omite ademas
la calibracion `parking_ready`, que es justo lo que la prueba viene a
producir; **el resto de calibraciones y `motion_enabled` se siguen
exigiendo**. Lo anuncia por consola al arrancar.

Esa puerta **solo la puede abrir el flag**: `validar_configuracion` rechaza
`corners_before_parking < 1`, asi que ningun JSON la activa por su cuenta.
Es excluyente con `--sin-parqueo`, que pide lo contrario.

Dos avisos de uso:

- Con `turn_direction: AUTO` el robot nunca entra al parqueo si arranca
  dentro de la bahia, porque no cruza ninguna linea de sentido y sin sentido
  no hay lado de bahia. Para esta prueba hay que fijar `LEFT` o `RIGHT`.
- Es opcion de banco, como `--arranque-inmediato`. La ronda oficial no la usa.

Claves nuevas en `configuracion.json` (`parking`):
`ultrasound_rear_enabled`, `ultrasound_rear_min_mm`, `ultrasound_rear_max_mm`.
Poniendo la primera en `false` se vuelve al comportamiento anterior sin
tocar codigo, que es lo que hace falta para comparar dos corridas.

### Reactividad de la evasion

Dos claves nuevas en `control`, ambas con respaldo al valor historico si no
estan:

- `avoid_steering_slew_deg_per_scan` (18,0). El slew de crucero son 6
  grados/barrido; a 10 Hz eso son cinco barridos —medio segundo, 8 cm a 40
  PWM— para llegar al tope de direccion. Contra un pilar a menos de un metro
  esa rampa se comia el margen: el robot pedia el angulo correcto y llegaba
  tarde.
- `obstacle_pursuit_kp_near` (1,6) entre `obstacle_pursuit_far_mm` (950) y
  `obstacle_pursuit_near_mm` (320). Con ganancia unica hay que elegir: si
  sirve de lejos, de cerca se queda corta porque el bearing crece rapido en
  los ultimos 30 cm; si sirve de cerca, de lejos oscila. Se interpola
  linealmente y satura en los dos extremos.

**Los cuatro valores son puntos de partida razonados, no calibraciones.**
Hay que medirlos en pista antes de darlos por buenos.

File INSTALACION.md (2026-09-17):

# Manual de Instalación — Team Los Cedros (WRO-FE 2026)

Esta guía documenta, paso a paso, cómo dejar una **Raspberry Pi 5** y una **Raspberry Pi Pico 2** nuevas en el mismo estado que las del robot de competencia, para que cualquier persona (juez, mentor, otro equipo) pueda reproducir el sistema completo desde cero.

> **El robot corre en una Raspberry Pi 5 desde el 03-09-2026.** Antes usaba una Pi 3B. La migración no fue una preferencia sino una decisión medida: el mismo pipeline de visión pasó de 67-72 ms a **4,8 ms** por cuadro a 640x360, y la edad del barrido LiDAR bajó de 16,0 ms de media a **0,1 ms** (ver sección 4.2 del [README principal](README.md#42-catálogo-de-componentes-y-justificación-de-selección)). Esta guía es para la Pi 5. Los pasos de la Pi 3B están en el historial de git si alguien necesita reconstruir aquella.

## Índice

1. [Requisitos previos](#1-requisitos-previos)
2. [Raspberry Pi 5 — Sistema operativo y dependencias](#2-raspberry-pi-5--sistema-operativo-y-dependencias)
3. [Raspberry Pi 5 — Cámara, LiDAR, I²C y permisos](#3-raspberry-pi-5--cámara-lidar-ic-y-permisos)
4. [Raspberry Pi Pico 2 — Firmware MicroPython](#4-raspberry-pi-pico-2--firmware-micropython)
5. [Desplegar los scripts en la Raspberry Pi 5](#5-desplegar-los-scripts-en-la-raspberry-pi-5)
6. [Arranque autónomo con systemd](#6-arranque-autónomo-con-systemd)
7. [Verificación rápida](#7-verificación-rápida)
8. [Cambiar de versión entre rondas](#8-cambiar-de-versión-entre-rondas)
9. [Problemas comunes](#9-problemas-comunes)

---

## 1. Requisitos previos

* **Raspberry Pi 5** con **Raspberry Pi OS (64-bit)**, Bookworm o superior, ya flasheada en la microSD. Usa [Raspberry Pi Imager](https://www.raspberrypi.com/software/) y, en las opciones avanzadas, habilita SSH y configura el usuario `pi` **antes** de grabar.
* **Raspberry Pi Pico 2** (RP2350), sin flashear.
* Laptop en la misma red que la Pi 5, con cliente SSH.
* Hardware ya montado siguiendo [`ENSAMBLAJE.md`](ENSAMBLAJE.md), y cableado según la sección 4 del [README principal](README.md#4-arquitectura-eléctrica-y-distribución-de-señales): RPLiDAR C1 por USB, Pi Camera Module 3 por CSI, Pico 2 por USB, botón de arranque en GPIO 21.

> **Si tienes las dos Raspberry encendidas, cuidado:** ambas responden al hostname `wro-fe`. Distínguelas por IP o por kernel — `uname -r` termina en `-2712` en la Pi 5 y en `-v8` en la Pi 3B. No te confíes del nombre que muestra la terminal al conectarte: es idéntico en las dos placas. Se perdió media jornada de trabajo el 03-09 por estar probando contra la equivocada sin saberlo.

---

## 2. Raspberry Pi 5 — Sistema operativo y dependencias

Conéctate por SSH (`ssh pi@<ip-de-la-pi>`) y actualiza el sistema:

```bash
sudo apt update && sudo apt full-upgrade -y
```

### 2.1 Dependencias de sistema (vía `apt`)

`picamera2` **no se instala con `pip`** — depende de las librerías nativas `libcamera` del sistema operativo, y la versión de PyPI se desincroniza con ellas. En Raspberry Pi OS Bookworm suele venir preinstalada, pero para dejarlo explícito:

```bash
sudo apt install -y python3-picamera2 python3-opencv python3-rpi-lgpio python3-pip python3-venv git --no-install-recommends
```

### 2.2 El paquete `RPi.GPIO` rompe el GPIO en la Pi 5

Este es el tropiezo que más tiempo costó de toda la migración, y es específico de la Pi 5.

**`RPi.GPIO` 0.7.1 (el paquete clásico de PyPI) no funciona en la Pi 5.** Falla con:

```
RuntimeError: Cannot determine SOC peripheral base address
```

El motivo es que la Pi 5 cambió el controlador de GPIO (chip RP1) y la librería vieja escribe directo a los registros del SoC. En la Pi 3B sí funciona, así que **si migras copiando `~/.local/` de una Pi 3B te llevas el problema contigo**.

La solución es el shim `python3-rpi-lgpio`, que ofrece la misma API `RPi.GPIO` por encima de `lgpio`. Ya se instaló en el paso 2.1; lo que hay que asegurar es que **no haya un `RPi.GPIO` de pip ganándole**:

```bash
pip uninstall -y RPi.GPIO        # si estaba instalado por pip, quitarlo
python3 -c "import RPi.GPIO as G; G.setmode(G.BCM); print('GPIO OK')"
```

> **Esto se rompe solo cada cierto tiempo.** Instalar `Adafruit-Blinka` con pip arrastra `RPi.GPIO` como dependencia y vuelve a romper el GPIO. Si el botón de arranque deja de responder después de instalar cualquier paquete, lo primero que hay que comprobar es esto. Blinka (`board`, `busio`) importa perfectamente sin `RPi.GPIO`.

### 2.3 Dependencias de Python (vía `pip`)

Raspberry Pi OS Bookworm bloquea `pip install` directo al entorno del sistema (PEP 668, error `externally-managed-environment`). Hay dos formas válidas — elige una:

**Opción A — entorno virtual con acceso a los paquetes de sistema (recomendada):**
```bash
python3 -m venv --system-site-packages ~/venv-wro
source ~/venv-wro/bin/activate
pip install -r src/pi5/requirements.txt
```

El flag `--system-site-packages` es clave: permite que el venv vea `picamera2` y el shim de GPIO instalados por `apt`, sin reinstalarlos por pip.

> Si usas el venv, actívalo antes de correr cualquier script y apunta `ExecStart` del servicio (sección 6) al Python del venv (`/home/pi/venv-wro/bin/python3`) en vez de `/usr/bin/python3`.

**Opción B — instalar directo al sistema (más simple, menos aislado):**
```bash
pip install --break-system-packages -r src/pi5/requirements.txt
```

[`src/pi5/requirements.txt`](src/pi5/requirements.txt) instala `opencv-python`, `numpy`, `pyserial` y `RPi.GPIO` (que en la Pi 5 lo resuelve el shim del paso 2.2).

---

## 3. Raspberry Pi 5 — Cámara, LiDAR, I²C y permisos

### 3.1 Cámara

En Raspberry Pi OS Bookworm la cámara ya no se habilita por `raspi-config`: `libcamera` la detecta sola. Verifica que responda:

```bash
libcamera-hello --list-cameras
```

Debe aparecer un `imx708` (Camera Module 3). Si no aparece, revisa que el cable plano esté bien insertado y con el contacto hacia el lado correcto.

### 3.2 I²C para la IMU

El MPU6050 cuelga de la Pico 2, no de la Pi, pero el bus I²C de la Pi se habilita igualmente para herramientas de diagnóstico. Añade a `/boot/firmware/config.txt`:

```
dtparam=i2c_arm=on
```

**Hace falta reiniciar** para que aparezca `/dev/i2c-1`. Guarda una copia del archivo antes de tocarlo.

### 3.3 Permisos de puerto serie

El usuario `pi` necesita pertenecer al grupo `dialout` para leer y escribir `/dev/ttyUSB0` (LiDAR) y `/dev/ttyACM0` (Pico 2) sin `sudo`:

```bash
sudo usermod -aG dialout pi
```

Cierra sesión y vuelve a entrar (o reinicia) para que el cambio tome efecto. Comprueba los tres dispositivos:

```bash
ls -l /dev/ttyUSB0 /dev/ttyACM0 /dev/video0
```

---

## 4. Raspberry Pi Pico 2 — Firmware MicroPython

### 4.1 Instalar MicroPython (una sola vez)

1. Descarga el firmware para **Pico 2 (RP2350)** desde [micropython.org/download/RPI_PICO2](https://micropython.org/download/RPI_PICO2/) (archivo `.uf2`). **No uses el del Pico original (RP2040)** — el chip es distinto.
2. Mantén presionado **BOOTSEL** mientras conectas el Pico 2 por USB. Aparecerá como una unidad externa (`RP2350`).
3. Arrastra el `.uf2` a esa unidad. El Pico se reinicia solo con MicroPython instalado.
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

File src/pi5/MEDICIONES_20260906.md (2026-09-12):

# Sesión de banco del 06-09-2026 — medidas del chasis, de la bahía y del movimiento

Sesión dedicada a **medir**, no a programar. El punto de partida era que la
maniobra de parqueo no cierra y que las constantes sobre las que se razonaba
—dimensiones del robot, tamaño de la bahía, velocidad por PWM— venían de
fuentes distintas y en varios casos no se habían comprobado nunca con regla.

Todo lo de aquí está volcado en `ronda_nueva/configuracion.json`, con la
justificación al lado de cada valor. Este documento explica **cómo** se midió
y **qué quedó sin cerrar**.

---
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

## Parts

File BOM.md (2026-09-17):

# Lista de Materiales (BOM) — Team Los Cedros, WRO Future Engineers 2026

Todo lo que hay que comprar y montar para reconstruir el vehículo desde cero, con la cantidad exacta, la función que cumple cada pieza y dónde está la justificación de por qué se eligió esa y no otra.

Esta lista es el índice de compra. El procedimiento de instalación del software está en [`INSTALACION.md`](INSTALACION.md), el cableado pin a pin en la [sección 4.3 del README](README.md#43-mapa-de-conexiones-calibrado-pinout), y la justificación comparativa de cada selección —incluidas las alternativas descartadas— en las [secciones 3.4 y 4.2](README.md#42-catálogo-de-componentes-y-justificación-de-selección).

**Los precios no se incluyen a propósito:** el equipo compra en Venezuela y en tiendas locales, donde el precio de un mismo componente varía tanto que una cifra publicada engañaría a quien intente reproducir el robot en otro país. Lo que sí se da es el modelo exacto, que es lo que permite cotizar.

---

## 1. Cómputo y sensado

| # | Componente | Modelo exacto | Cant. | Función en el vehículo |
| :---: | :--- | :--- | :---: | :--- |
| 1 | Computadora de alto nivel | **Raspberry Pi 5** (4 GB o superior) | 1 | Visión, procesado del LiDAR y máquina de estados de navegación. Sustituyó a la Pi 3B el 03-09-2026 por cómputo medido: el mismo procesado de imagen pasó de 67-72 ms a **4,8 ms** por cuadro. |
| 2 | Microcontrolador de tiempo real | **Raspberry Pi Pico 2** (RP2350) | 1 | Genera el PWM del servo y del motor, integra el giroscopio y aplica el *watchdog* de 500 ms. Aísla el lazo físico del *jitter* de Linux. |
| 3 | Telémetro láser rotativo | **RPLiDAR C1** | 1 | Paredes, esquinas y detección geométrica de los pilares en 360°. Conectado por USB a 460 800 bps. |
| 4 | Cámara | **Raspberry Pi Camera Module 3** (sensor IMX708, versión **estándar**) | 1 | Color de los pilares y lectura de las líneas de pista. Conecta por CSI de 15 pines. |
| 5 | Unidad inercial | **MPU6050** (giroscopio + acelerómetro, I²C) | 1 | *Yaw* del vehículo para contar vueltas y sostener el rumbo. Va soldada a la placa perforada, alineada con el eje longitudinal. |
| 6 | Ultrasonido | **HC-SR04** | 1 | Única medida real hacia atrás: el mástil del LiDAR le tapa el sector 140-213°. Imprescindible para el estacionamiento. |
| 7 | Pulsador de arranque | Pulsador momentáneo NA | 1 | Da la salida en la ronda oficial (`GPIO 21` de la Pi 5, con *pull-up* interno). |
| 8 | Sensor de color de piso | **TCS3472** (I²C) | 1 | Montado **al frente del vehículo**, por delante del eje delantero y mirando el piso, no bajo el chasis: leer la línea antes de pisarla da margen de reacción. Clasifica la línea de esquina como `AZUL` o `NARANJA`; el **orden** en que se cruza la pareja de una misma esquina es la única evidencia absoluta del sentido de carrera. |
| 10 | Almacenamiento | microSD 32 GB clase 10 o superior | 1 | Sistema operativo y registros de telemetría de cada corrida. |
| 26 | Acelerador de inferencia | **Raspberry Pi AI HAT+ 26 TOPS** (módulo Hailo-8) | 1 | Reconocimiento de pilares por red neuronal, sobre el conector de 40 pines de la Pi 5. Medido en banco el 14-09-2026: **310 FPS** y **12,8 ms** de latencia de *pipeline*. Sustituye únicamente la clasificación de pilares; las líneas de pista y la geometría del LiDAR no lo usan ([sección 5.5 del README](README.md#55-reconocimiento-de-pilares-por-red-neuronal-acelerador-hailo)). |

> **Sobre la cámara: es la Module 3 estándar, no la Wide.** Conviene decirlo porque el catálogo de la Wide anuncia 102° y eso induce a comprar la equivocada. La medida propia está en [`optica.py`](src/pi5/ronda_curvas/optica.py): emparejando una esquina que el LiDAR sitúa en −21,5° con su borde en el frame sale un **HFOV efectivo de 53,8°**, que concuerda con los 51,9° previstos para la Module 3 estándar recortada a 4:3 y no con los 85,6° de la Wide.

## 2. Actuación y potencia

| # | Componente | Modelo exacto | Cant. | Función en el vehículo |
| :---: | :--- | :--- | :---: | :--- |
| 9 | Servomotor de dirección | **Geekservo Servo** | 1 | Dirección Ackermann. Se eligió por acople nativo a vigas Technic: cualquier adaptador impreso añade holgura al tren delantero. |
| 11 | Motor de tracción | **Geekservo DC** | 1 | Tracción trasera. Par de bloqueo de 2,4 kg·cm, con margen de **2,18×** sobre la masa del vehículo. |
| 12 | Driver de motor | **TB6612FNG** (puente H doble) | 1 | Etapa de potencia del motor DC. Elegido sobre el L298N por topología MOSFET: menos caída de tensión y menos calor. |

## 3. Alimentación y regulación

| # | Componente | Modelo exacto | Cant. | Alimenta |
| :---: | :--- | :--- | :---: | :--- |
| 13 | Celdas de batería | **Li-ion 21700** en configuración **2S** (7,4-8,4 V) | 2 | Toda la energía del vehículo. |
| 14 | Regulador reductor | **XL4016** (salida 5,1 V / 8 A) | 1 | Raspberry Pi 5, cámara y RPLiDAR C1. |
| 15 | Regulador reductor | **XL1509** (salida 6,0 V / 2 A) | 1 | Servomotor de dirección, en línea limpia y separada de la lógica. |
| 16 | Portapilas 2S | Portaceldas 21700 doble | 1 | Sujeción mecánica y contacto de las celdas. |

> **La separación en tres etapas no es opcional.** Es lo que evita que el pico de corriente del motor provoque un reinicio de la Raspberry a mitad de carrera. El consumo real medido con multímetro el 06-09-2026 es de **1,39 A en marcha**, **0,61 A en reposo** y **0,21 A con la Pi apagada**; restando estados se deduce que la Pi 5 consume 0,40 A y la tracción 0,78 A. El desglose completo está en la [sección 4.4 del README](README.md#44-presupuesto-de-consumo-energético-y-gestión-de-corriente).

## 4. Estructura mecánica

| # | Componente | Detalle | Cant. | Función |
| :---: | :--- | :--- | :---: | :--- |
| 17 | Chasis | **LEGO Technic, 83 piezas** — listado completo con Design ID de BrickLink en [`models/Chasis-LEGO-V2/`](models/Chasis-LEGO-V2/README.md) | 1 | Estructura del vehículo. El archivo CAD `.io` es reproducible pieza por pieza con BrickLink Studio, que es gratuito. |
| 18 | Ruedas y neumáticos | LEGO, Design ID `bl_56145c01` | 4 | Dos motrices traseras y dos directrices delanteras. |
| 19 | Mástil del LiDAR | Estructura Technic incluida en las 83 piezas | 1 | Eleva el plano de barrido a **69 mm del piso**, altura a la que el haz corta tanto los pilares como las paredes (100 mm ambos según reglamento). |
| 20 | Placa perforada | Placa de prototipado para soldadura | 1 | Soporte permanente de Pico 2, TB6612FNG y MPU6050. Se soldó en vez de usar *jumpers* porque la vibración provocaba falsos contactos. **Va en el piso del chasis, debajo de la Raspberry Pi 5**, para dejarle a esta la planta superior donde se monta el AI HAT+. |

> El chasis V1 era un monocasco impreso en 3D de ≈800 g. Se sustituyó por el actual de vigas Technic: **23,37 % menos masa**, menos resonancia en el soporte de la cámara y reconfiguración rápida en boxes sin reimprimir. Los STL del V1 se conservan en [`models/V1/`](models/V1/README.md) como registro del proceso de iteración.

## 5. Cableado e integración

| # | Componente | Detalle | Cant. |
| :---: | :--- | :--- | :---: |
| 21 | Cable plano CSI | 15 pines, para Camera Module 3 | 1 |
| 22 | Cable USB-A a micro-USB | Corto, Pi 5 ↔ Pico 2 (VCP a 115 200 bps) | 1 |
| 23 | Cable USB del LiDAR | El que incluye el RPLiDAR C1 | 1 |
| 24 | Cable de conexión | Calibre 22 AWG para señal, 18 AWG para potencia | — |
| 25 | Interruptor general | Conmutador de corte de batería | 1 |

> **Todas las tierras confluyen en estrella en un único punto central.** Esto unifica los umbrales lógicos entre las tres etapas y drena el ruido de conmutación del motor, que de otro modo aparece como falsos flancos en las líneas digitales.

## 6. Herramientas necesarias para el montaje y la puesta a punto

No forman parte del vehículo, pero sin ellas no se puede reproducir ni verificar el resultado.

| Herramienta | Para qué se usa en este proyecto |
| :--- | :--- |
| Soldador y estaño | Placa perforada y líneas de potencia. |
| Multímetro | Presupuesto de corriente de la sección 4.4. El del equipo es un ANENG M118A. |
| Computadora con SSH | Despliegue del código y lectura de la telemetría de cada corrida. |
| Cámara cenital | Grabar cada corrida y correlacionarla con el CSV de telemetría. Es el método de trabajo del equipo: cuando el registro y el vídeo se contradicen, **manda el vídeo**. |
| Regla o calibre | Verificar la altura del plano del LiDAR (69 mm) y la geometría del chasis. Varias medidas del montaje resultaron desviadas respecto a lo supuesto. |

---

## Resumen de cantidades

| Bloque | Piezas distintas | Unidades |
| :--- | :---: | :---: |
| Cómputo y sensado | 10 | 10 |
| Actuación y potencia | 3 | 3 |
| Alimentación | 4 | 5 |
| Estructura mecánica | 4 | 83 piezas Technic + placa |
| Cableado | 5 | — |

El vehículo completo, en su configuración actual (V3), pesa **720 g**. El chasis de vigas Technic es el mismo que el de la V2 —que pesaba 613 g como vehículo completo—; los 107 g de diferencia son la electrónica que se montó encima: Raspberry Pi 5 con su carcasa y ventilador, el mástil del LiDAR y el ultrasonido trasero.

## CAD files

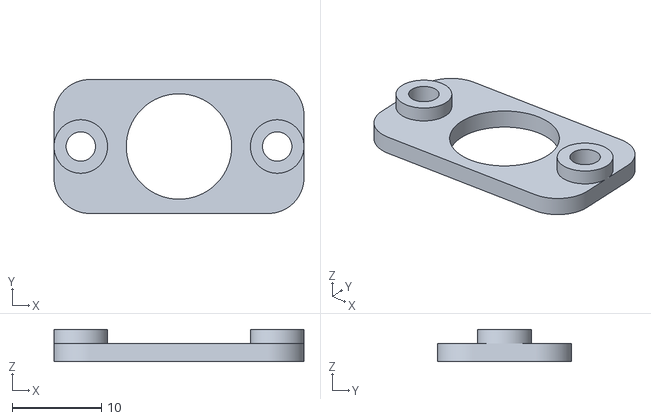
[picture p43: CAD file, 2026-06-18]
models/V1/SoporteExterior_eje.stl
28.0 x 15.0 x 3.60

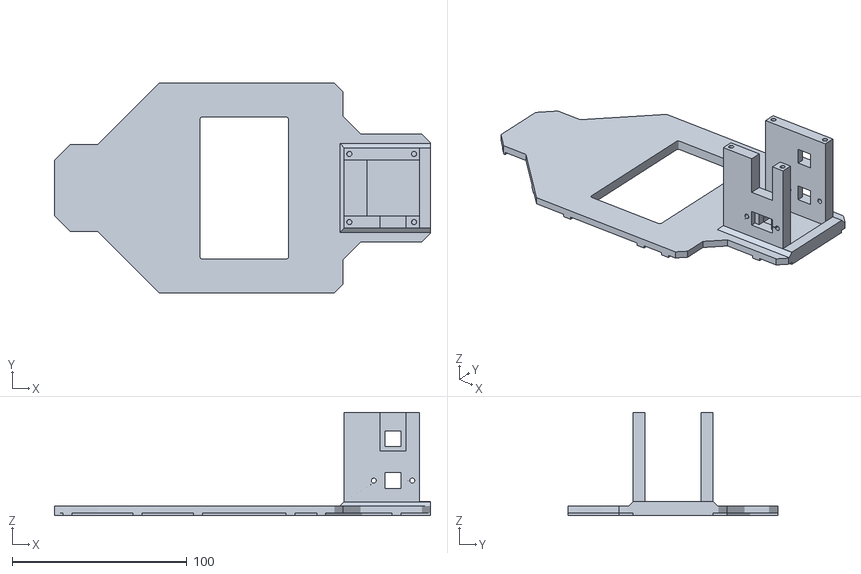
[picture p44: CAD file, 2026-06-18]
models/V1/Chasis.stl
215.0 x 120.0 x 59.0

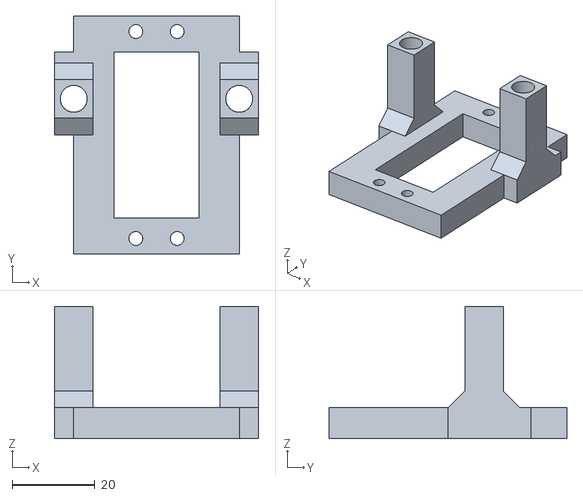
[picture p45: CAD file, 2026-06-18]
models/V1/Base_servo.stl
49.4 x 57.5 x 32.0

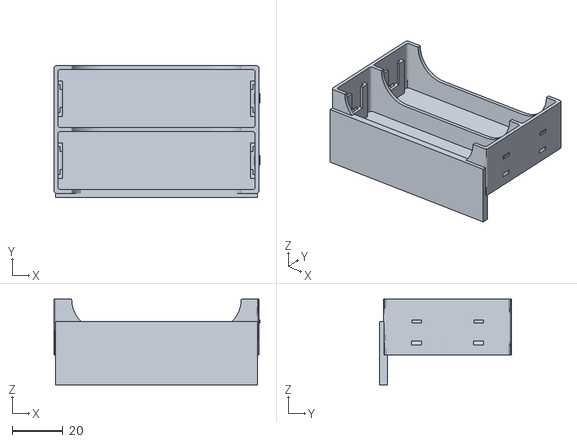
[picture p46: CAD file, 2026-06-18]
models/V1/Portapilas.stl
81.4 x 52.0 x 33.9

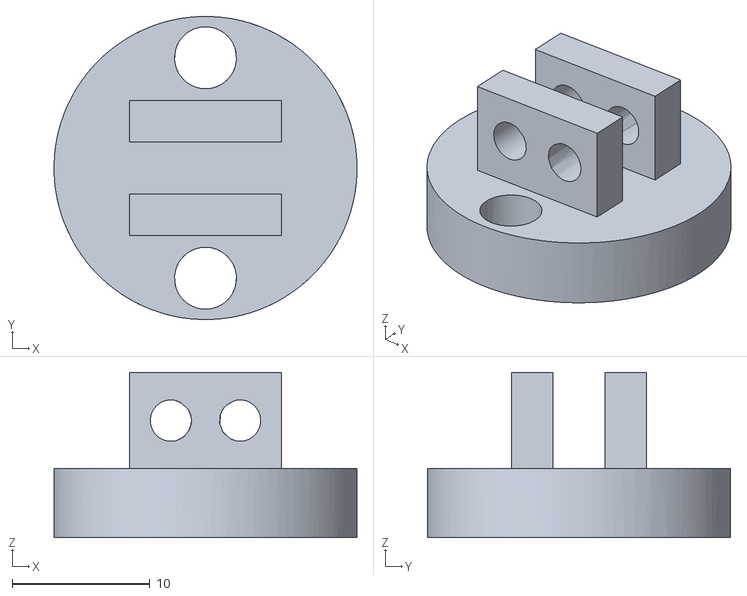
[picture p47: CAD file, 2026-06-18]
models/V1/Base_llanta.stl
22.0 x 22.0 x 12.0

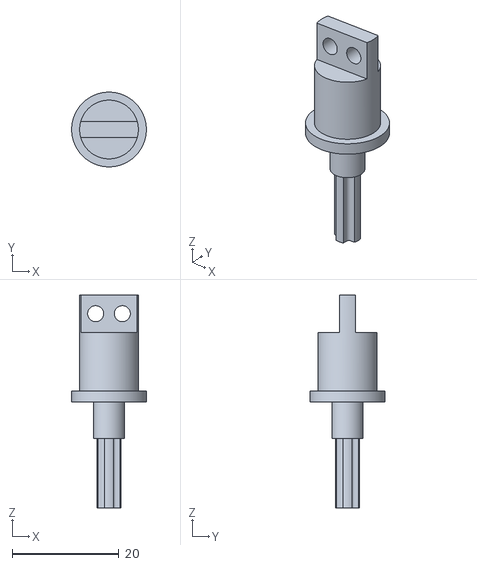
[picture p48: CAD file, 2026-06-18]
models/V1/Eje_llanta.stl
14.0 x 14.0 x 39.9

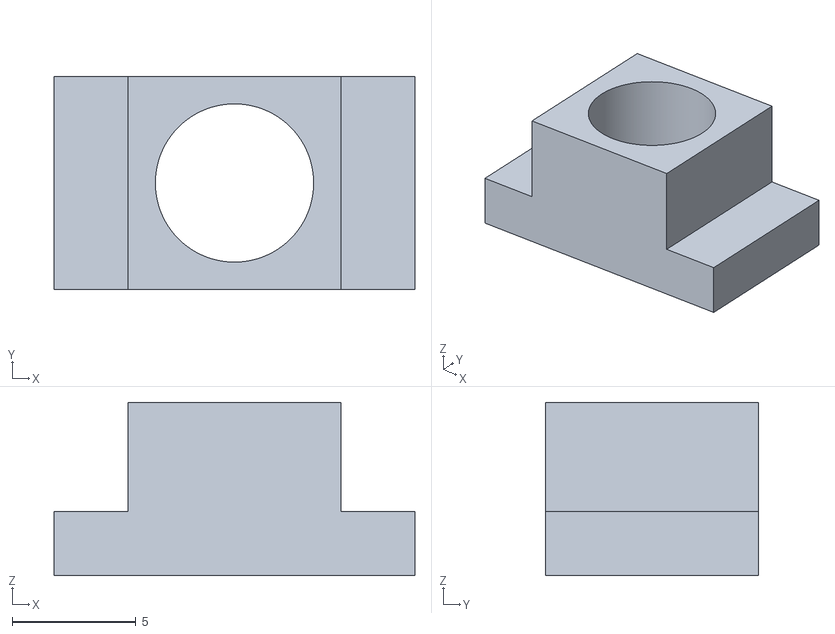
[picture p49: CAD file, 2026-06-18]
models/V1/SopoteInterior_Eje.stl
14.6 x 8.60 x 7.00

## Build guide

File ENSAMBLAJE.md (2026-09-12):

# Manual de Ensamblaje — Team Los Cedros (WRO-FE 2026)

Cómo montar el vehículo desde las piezas sueltas hasta la primera corrida, en el orden en que conviene hacerlo y con la comprobación que cierra cada etapa.

Este manual cubre el **montaje físico**. Lo que hay que comprar está en [`BOM.md`](BOM.md); la instalación del software, en [`INSTALACION.md`](INSTALACION.md); el flujo de señales completo, en el [diagrama de bloques](schemes/Diagrama_Bloques_Senales.svg) de la sección 4 del [README](README.md#4-arquitectura-eléctrica-y-distribución-de-señales).

> **El orden importa.** Está pensado para que cada etapa se pueda verificar antes de que la siguiente la tape: la placa perforada se prueba antes de atornillarla al chasis, y el LiDAR se mide antes de montar la cámara debajo. Saltarse el orden no rompe nada, pero obliga a desmontar para diagnosticar.

---

## Etapa 0 — Antes de tocar una pieza

Tres decisiones que condicionan todo lo demás y que cuesta caro cambiar a mitad de montaje:

* **El chasis es LEGO Technic, no impreso.** La versión impresa (V1) transmitía la vibración de los motores directa a la cámara y descalibraba la visión. Las vigas de fricción absorben ese ruido por flexión y permiten recolocar un sensor en boxes sin reimprimir nada.
* **La electrónica va soldada a una placa perforada, no con cables de puente.** Los *jumpers* sueltos daban falsos contactos por vibración. Es la diferencia entre un robot que falla una vez cada diez corridas sin motivo aparente y uno que no.
* **La alimentación va en tres etapas separadas.** Una sola línea para todo provoca reinicios de la Raspberry cuando el motor pide par. No es una mejora opcional: es lo que hace que el robot termine la ronda.

---

## Etapa 1 — Chasis

El chasis son **83 piezas de LEGO Technic**. El archivo CAD reproducible está en [`models/Chasis-LEGO-V2/Chasis-V2.io`](models/Chasis-LEGO-V2/), y el listado completo con el *Design ID* de BrickLink de cada pieza, en el [README de esa carpeta](models/Chasis-LEGO-V2/README.md).

Para seguir el montaje pieza a pieza, abre el `.io` con [BrickLink Studio](https://www.bricklink.com/v3/studio/download.page) (gratuito) y usa su generador de instrucciones: produce la vista explosionada y los pasos numerados a partir del propio modelo, así que las instrucciones nunca se desincronizan del diseño.

**Geometría que hay que verificar con regla al terminar,** porque de ella dependen la evasión y el estacionamiento:

| Medida | Valor | Por qué importa |
| :--- | :---: | :--- |
| Largo total del vehículo | **242 mm** | Fija el tamaño de plaza que el robot cree tener. |
| Ancho total | **138 mm** | Con él se calcula la holgura contra cada muro. |
| Eje del LiDAR a cada costado | **68 mm** | Es simétrico. Suponerlo asimétrico bloqueó la maniobra de estacionamiento durante toda una jornada. |
| Eje del LiDAR al morro | **54 mm** | Margen frontal de las maniobras. |
| Eje del LiDAR a la cola | **188 mm** | Margen en marcha atrás. |

## Etapa 2 — Dirección y tracción

1. **Servo de dirección.** Acopla el Geekservo directo al `base_servo` del eje delantero. No uses adaptadores impresos entre servo y viga: cada adaptador añade holgura, y la holgura en la dirección se convierte en error de trayectoria que ningún control puede corregir.
2. **Motor de tracción.** El Geekservo DC va al eje trasero. Los neumáticos son de caucho, no de plástico: los rígidos patinan al acelerar y disipan la potencia en calor.
3. **Ruedas.** Cuatro, una por esquina. Las dos delanteras dirigen, las dos traseras traccionan.

**El montaje, fotografiado.** El tren de dirección se arma como un módulo aparte y se acopla al chasis ya montado. Las imágenes van en el orden en que se tomaron durante el armado:

| | | |
| :---: | :---: | :---: |
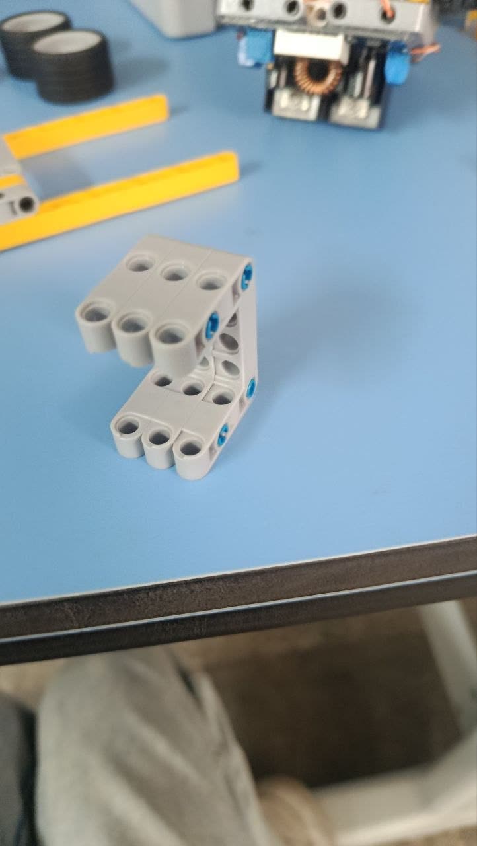
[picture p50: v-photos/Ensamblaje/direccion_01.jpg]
Montaje de la direccion, paso 1
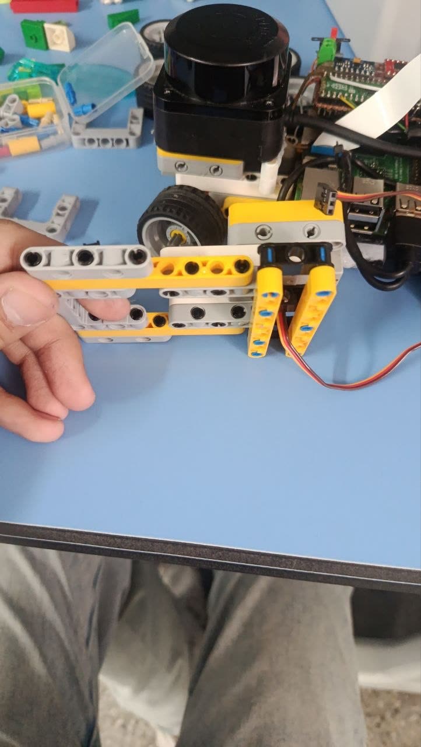
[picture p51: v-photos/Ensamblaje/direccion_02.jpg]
Montaje de la direccion, paso 2
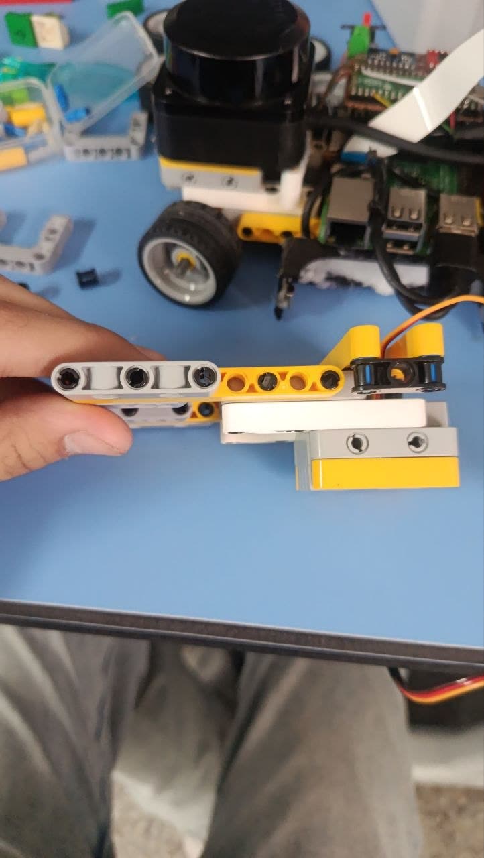
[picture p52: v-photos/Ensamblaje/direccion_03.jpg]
Montaje de la direccion, paso 3
|  |  |  |
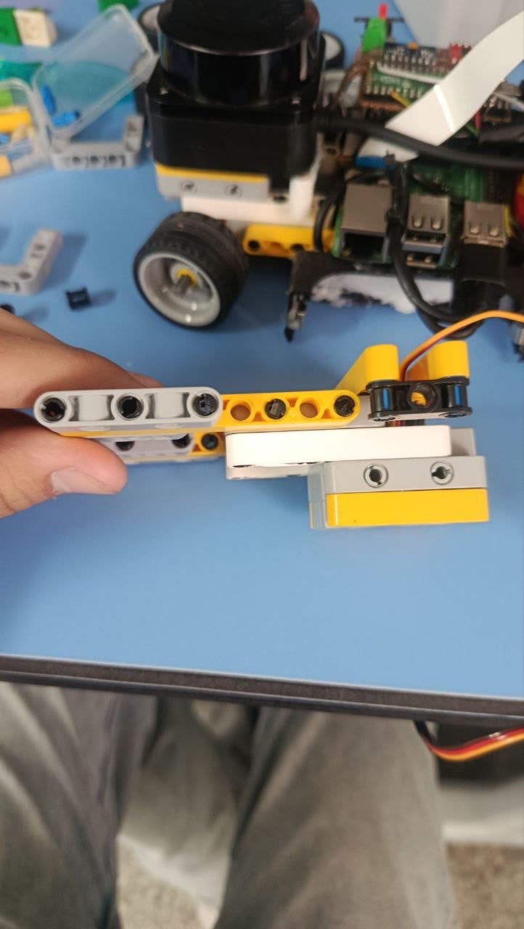
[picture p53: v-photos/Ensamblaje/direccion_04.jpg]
Montaje de la direccion, paso 4
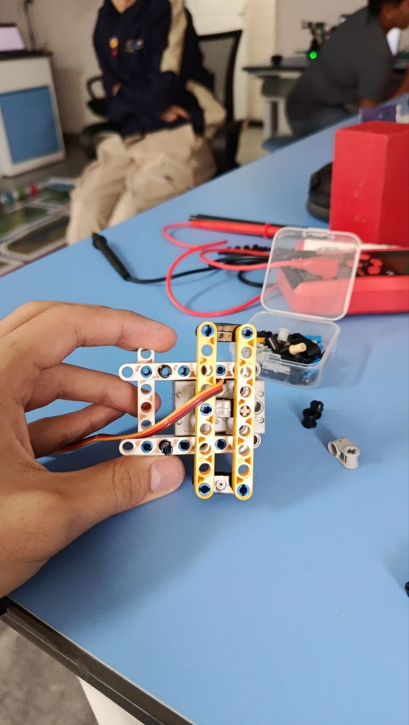
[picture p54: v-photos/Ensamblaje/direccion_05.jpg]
Montaje de la direccion, paso 5
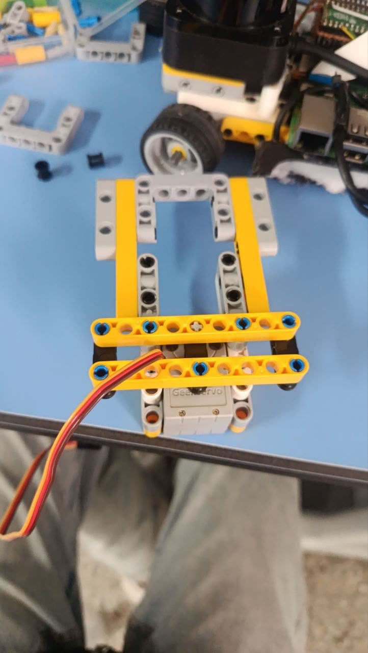
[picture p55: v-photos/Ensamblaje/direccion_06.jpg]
Montaje de la direccion, paso 6
|  |  |  |
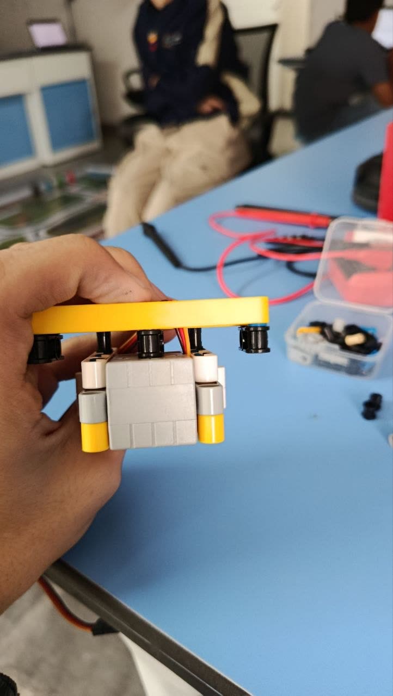
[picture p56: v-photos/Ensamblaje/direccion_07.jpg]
Montaje de la direccion, paso 7
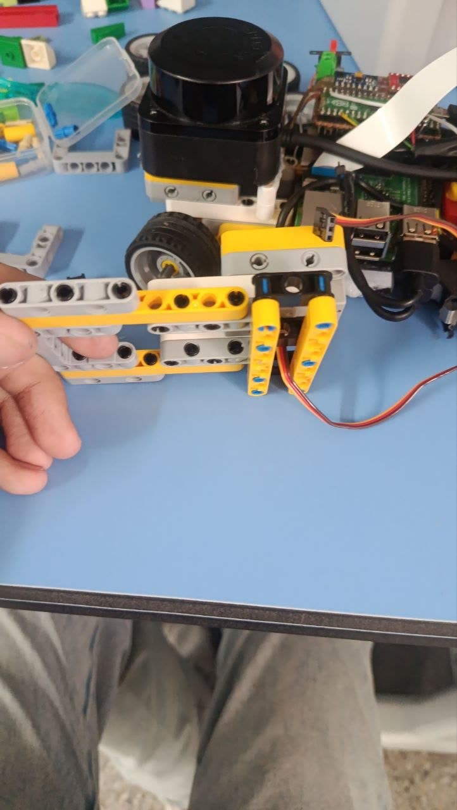
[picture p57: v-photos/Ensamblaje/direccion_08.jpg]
Montaje de la direccion, paso 8
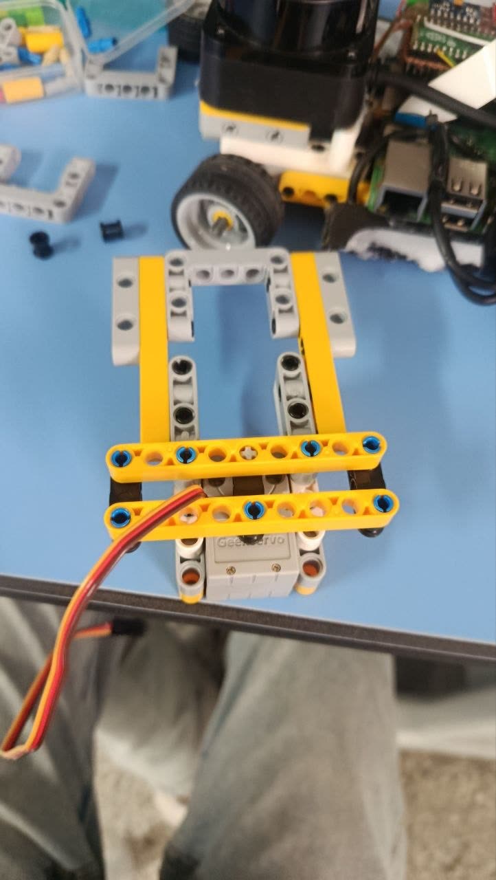
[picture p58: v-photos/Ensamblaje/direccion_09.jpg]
Montaje de la direccion, paso 9
|  |  |  |
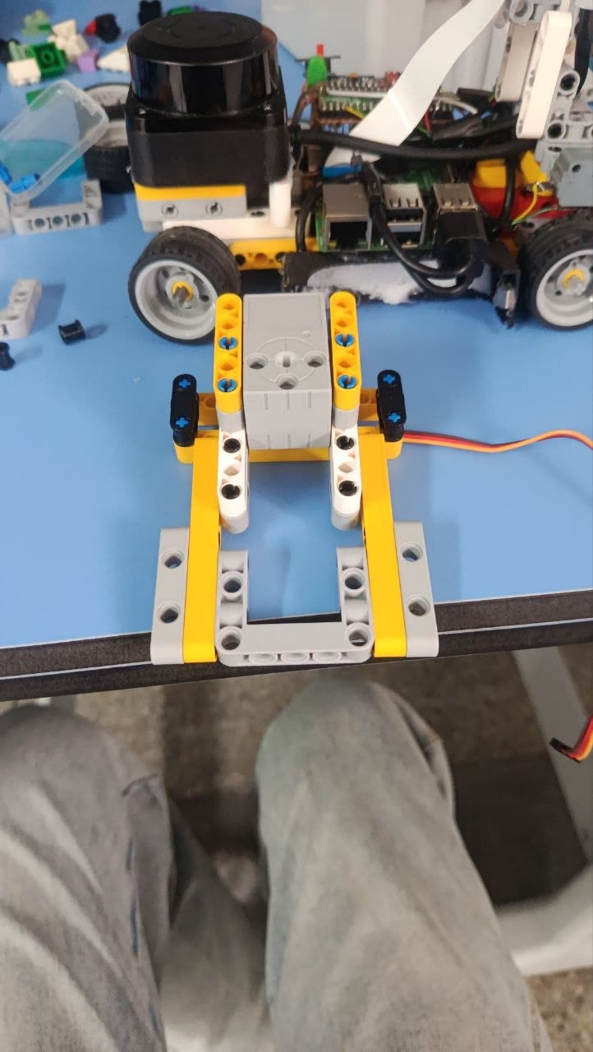
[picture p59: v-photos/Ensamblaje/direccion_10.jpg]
Montaje de la direccion, paso 10
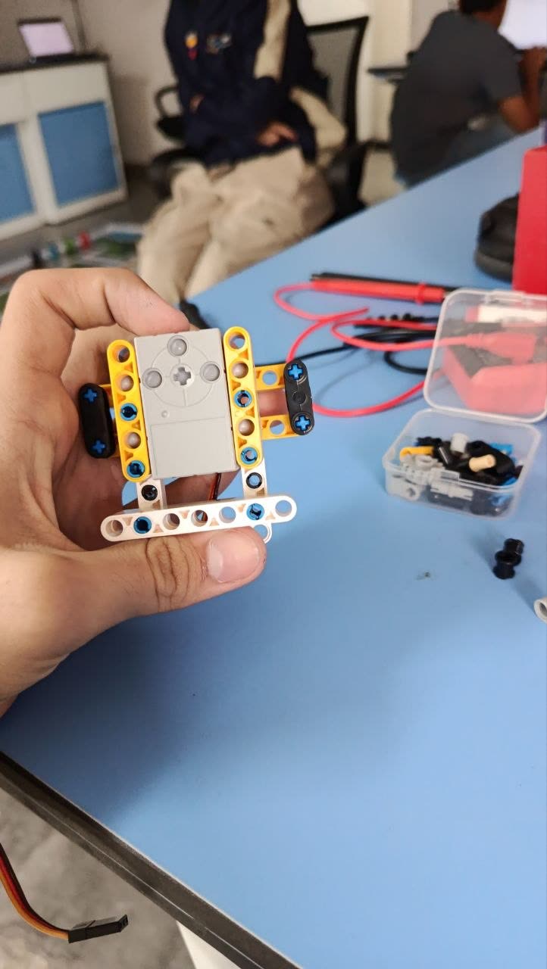
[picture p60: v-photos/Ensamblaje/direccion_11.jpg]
Montaje de la direccion, paso 11
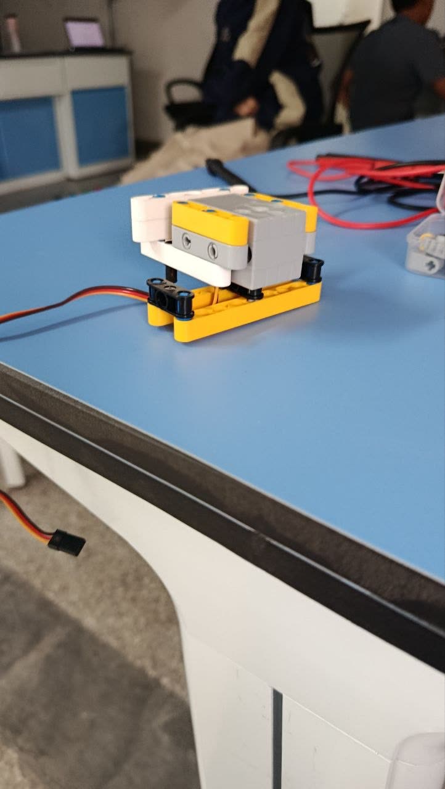
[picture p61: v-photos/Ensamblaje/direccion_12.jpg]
Montaje de la direccion, paso 12
|  |  |  |
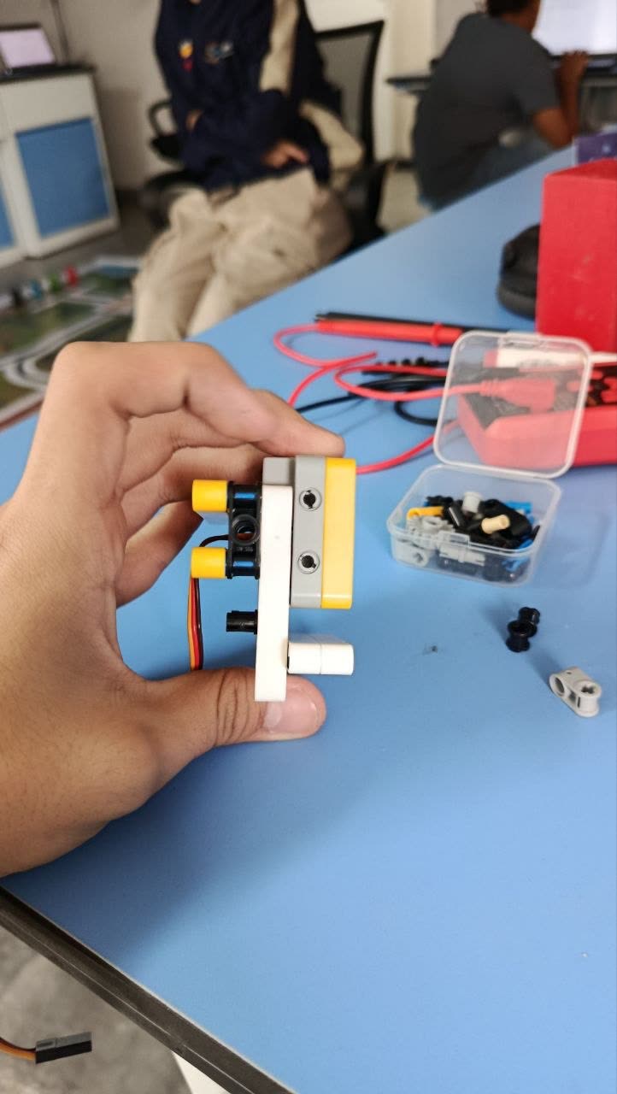
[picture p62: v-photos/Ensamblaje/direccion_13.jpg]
Montaje de la direccion, paso 13
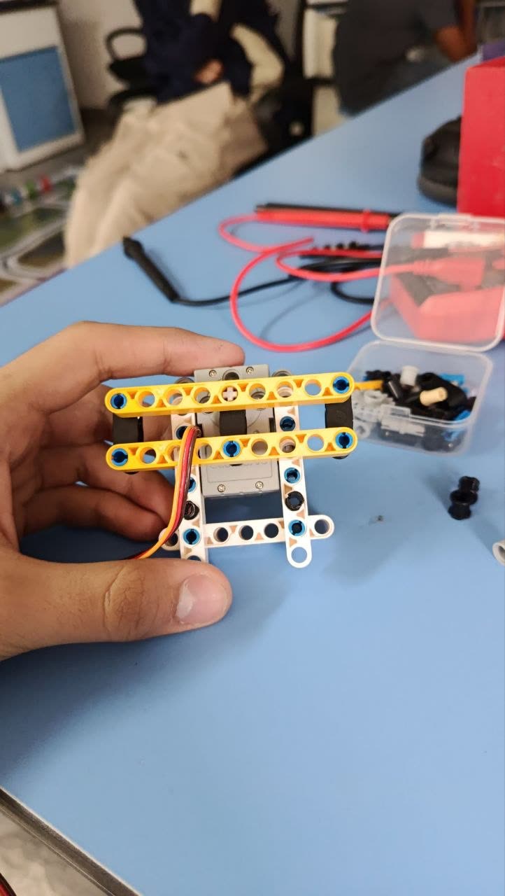
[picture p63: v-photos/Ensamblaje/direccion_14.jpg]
Montaje de la direccion, paso 14
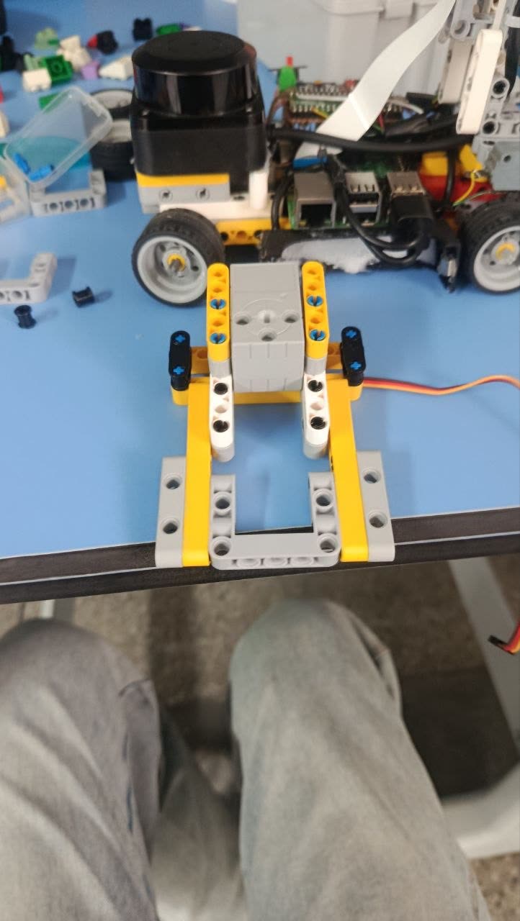
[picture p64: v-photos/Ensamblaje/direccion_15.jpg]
Montaje de la direccion, paso 15
|  |  |  |

Fíjate en las dos últimas: el servo queda **encajado entre las vigas y sujeto por los dos lados**, no colgando de un solo punto. Es lo que impide que el par de la dirección haga palanca sobre un único pin y meta holgura en el sistema.

**Comprobación de esta etapa** (con el vehículo levantado, las ruedas al aire):

```bash
cd ~/ronda_curvas
python3 test_recorrido_servo.py     # barre el servo de tope a tope
python3 medir_radio.py              # mide el radio de giro real
```

El radio real debe rondar los **242 mm a la izquierda y 244 a la derecha**. Que salgan casi iguales es lo que se espera de una Ackermann bien montada; una diferencia grande delata holgura o un tope mal puesto.

## Etapa 3 — Placa perforada

Suelda sobre la placa perforada, **antes de montarla en el chasis**, estos tres componentes:

* **Raspberry Pi Pico 2**
* **Driver TB6612FNG**
* **MPU6050**

| Capa superior — Pico 2 + MPU6050 | Capa inferior — soldadura y buses |
| :---: | :---: |
| Capa superior de la placa perforada | Capa inferior de la placa perforada |

La IMU tiene una condición de montaje que no es negociable: **alineada con el eje longitudinal del chasis**. Así la lectura del eje Z corresponde exactamente al giro del vehículo y no hay que compensar ninguna desalineación por software. Móntala torcida y todo el conteo de vueltas hereda ese error.

Sigue el pinout de la [sección 4.3 del README](README.md#43-mapa-de-conexiones-calibrado-pinout). Resumen de lo que sale de la Pico:

| Destino | Pines |
| :--- | :--- |
| Servo de dirección | `GP12` (PWM 50 Hz) |
| TB6612FNG | `GP22` PWM · `GP26`/`GP27` dirección · `GP28` habilitación |
| MPU6050 | `GP16` SDA / `GP17` SCL (I²C0, 400 kHz) |
| TCS3472 | `GP18` SDA / `GP19` SCL (I²C1, 100 kHz) |
| HC-SR04 | `GP14` disparo / `GP15` eco |

> El bus del sensor de color va a **100 kHz y no a 400** como el de la IMU. El TCS3472 no sostiene 400 kHz de forma fiable, y a esa velocidad falla de forma intermitente, que es la peor manera de fallar.

## Etapa 4 — Alimentación

Monta las tres etapas **antes** de conectar nada de lógica, y comprueba cada salida con el multímetro con la carga desconectada:

| Etapa | Entrada | Salida esperada | Alimenta |
| :--- | :---: | :---: | :--- |
| Directo de batería | 2S 21700, 7,4-8,4 V | — | TB6612FNG (potencia del motor) |
| **XL4016** | 7,4-8,4 V | **5,1 V** | Raspberry Pi 5, cámara, RPLiDAR C1 |
| **XL1509** | 7,4-8,4 V | **6,0 V** | Servo de dirección |

Los reguladores son ajustables: **ponlos a tensión antes de conectarles la carga.** Un XL4016 que salga de fábrica a 12 V destruye la Raspberry en el primer arranque.

**Todas las tierras van a un único punto central, en estrella.** No encadenes masas de un módulo a otro: eso crea diferencias de potencial entre etapas y el ruido de conmutación del motor aparece como falsos flancos en las líneas digitales.

**Comprobación de esta etapa** — con el vehículo montado y el multímetro en serie con la batería, el consumo debe parecerse a esto:

| Estado | Corriente |
| :--- | :---: |
| Con la Pi apagada (solo Pico, sensores y potencia) | ~0,21 A |
| Sistema encendido, sin tracción | ~0,61 A |
| En marcha | ~1,39 A |

## Etapa 5 — Sensores

**Mástil del LiDAR.** El RPLiDAR C1 va elevado sobre un mástil, por encima de la cámara. La altura no es libre: el plano de barrido tiene que quedar a **69 mm del piso**, que es donde el haz corta tanto los pilares como las paredes (ambos de 100 mm de alto según el reglamento).

El mástil tiene un coste conocido: **el LiDAR se ve a sí mismo**. Mídelo y confírmalo:

```bash
python3 ~/WRO-FE-26/src/pi5/herramientas/diag_mastil.py
```

Debe encontrar el mástil en torno a **141-212° a 35-68 mm**, presente en casi todos los barridos. Ese sector se enmascara por software; si tu montaje lo sitúa en otro rango, hay que actualizar la máscara o el robot creerá tener una pared detrás.

**Cámara.** Al frente, debajo del LiDAR y **retrasada respecto al parachoques**, para que un golpe contra el perímetro no la reciba directa — en la V1 eso destruyó el módulo. Montada a **0° de inclinación**, mirando derecho al frente, sin inclinarla hacia el piso.

**Ultrasonido trasero.** Va en la cola, y apunta su posición exacta: está **34 mm por delante del punto más atrasado del robot**, así que la holgura real de la culata es su lectura menos esos 34 mm. Es la única medida real hacia atrás, porque el mástil ciega al LiDAR justo en ese sector.

**Sensor de color.** Al frente del vehículo, por delante del eje delantero y mirando el piso. No va bajo el chasis: adelantarlo hace que la línea se lea antes de pisarla, y esa anticipación es la que permite reaccionar en vez de enterarse cuando ya se cruzó.

**Comprobación de esta etapa.** Las pruebas de banco viven en dos sitios: las de `ronda_curvas/` se despliegan con el resto del código, y las de `src/pi5/herramientas/` se corren desde el clon del repositorio.

```bash
cd ~/ronda_curvas
python3 diag_lidar_360.py           # el barrido completo, sector a sector
python3 test_sectores_trasera.py    # coherencia entre el ultrasonido y el LiDAR

# este vive en el clon del repositorio, no en la carpeta de trabajo:
python3 ~/WRO-FE-26/src/pi5/herramientas/diag_eco_volante.py
```

`diag_eco_volante.py` no debería encontrar **ningún punto por debajo de 500 mm** en los sectores laterales con el volante recto ni a los topes. Si aparecen, el LiDAR está viendo su propia rueda y la maniobra de estacionamiento se bloqueará contra un obstáculo que no existe.

## Etapa 6 — Calibración antes de la primera corrida

Tres calibraciones que el robot no puede deducir solo:

```bash
cd ~/ronda_curvas
python3 calib_hsv.py            # umbrales de rojo y verde bajo la luz real del recinto
python3 calibrar_lineas.py      # orden de las líneas de esquina, empujando el robot una vuelta a mano
python3 medir_fov.py            # campo de visión efectivo de la cámara
```

* **Los umbrales HSV se recalibran en cada sede.** La luz de los boxes no es la de la pista oficial, y un umbral que funcionaba ayer deja de ver el pilar rojo hoy.
* **`calibrar_lineas.py` se corre una sola vez** y fija en qué orden se cruzan las líneas naranja y azul. Sin esa calibración el sistema **ignora** esa fuente por completo en vez de inventarse un sentido.
* **El campo de visión se mide, no se copia del catálogo.** El de esta cámara son **53,8° efectivos**, no los 102° que anuncia la hoja de datos de la versión *Wide*: el sensor recorta antes de escalar. Dar por bueno el catálogo infla el rumbo calculado de cada pilar 2,3 veces.

## Etapa 7 — Primera corrida

Con el software ya instalado ([`INSTALACION.md`](INSTALACION.md)):

```bash
bash ~/correr_completa.sh
```

Lo que tiene que pasar, en orden:

1. **El LED de la Pico parpadea.** Significa que todo cargó y espera.
2. **Pulsas el botón** de `GPIO 21`: el LED se apaga y arranca la secuencia.
3. El robot informa de lo que ve antes de moverse. Si está mal colocado en la plaza, **aborta y dice cuántos milímetros moverlo y hacia dónde**.
4. Sale del estacionamiento, corre las tres vueltas contando las líneas de pista y vuelve a parar en el cuadrante de salida.

> **Para detener una corrida a mitad, usa siempre SIGINT y nunca SIGTERM.** Solo SIGINT está manejado; un SIGTERM mata el proceso dejando el motor girando con la última consigna. Desde otra máquina: `ssh pi@<ip> 'pkill -INT -f ronda_camara'`.

---

## Checklist final

Antes de dar el vehículo por montado:

- [ ] El plano del LiDAR está a 69 mm del piso, medido con regla.
- [ ] `diag_mastil.py` sitúa el mástil dentro del sector enmascarado.
- [ ] `diag_eco_volante.py` no ve la rueda propia a ningún ángulo de volante.
- [ ] Las tres salidas de alimentación dan 5,1 V, 6,0 V y tensión de batería.
- [ ] Todas las masas confluyen en un solo punto.
- [ ] La IMU está alineada con el eje longitudinal.
- [ ] El radio de giro real ronda los 242/244 mm a cada lado.
- [ ] Los umbrales HSV están recalibrados bajo la luz del recinto.
- [ ] `calibrar_lineas.py` se corrió al menos una vez.
- [ ] El LED de la Pico parpadea al lanzar y el botón arranca la secuencia.

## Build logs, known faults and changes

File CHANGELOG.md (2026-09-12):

# Registro de Cambios

Notas de versión del proyecto, basadas en los hitos reales del historial de
commits (ver `git log`). Formato inspirado en [Keep a Changelog](https://keepachangelog.com/es-ES/1.1.0/).
Cada versión referencia los commits representativos de ese hito para
poder auditar el cambio exacto con `git show <hash>`.

## [v0.11.0] — 2026-09-12 — Calibración en pista, selección de ronda y saneamiento de la documentación

Versión orientada a **operar el vehículo en competencia**: recalibrar el color
sin editar código, cambiar de ronda sin editar el servicio, y dejar el
repositorio sin defectos silenciosos.

### Agregado

- `ronda_curvas/calibrador_web.py`: calibrador de color por navegador. Sirve en
  el puerto 8080 la cámara y la máscara lado a lado, con el **área del blob en
  números**, que es el valor que decide si el robot ve el pilar o no. Guarda en
  `calibracion.json`, que `vision.py` lee al arrancar; si el archivo falta o está
  corrupto se usan los valores del código, de modo que el archivo solo puede
  mejorar la calibración y nunca dejar el vehículo sin una. Se calibran los
  cuatro colores, **incluidas las líneas naranja y azul del piso**, de las que
  sale el conteo de vueltas.
- `ronda.sh`, `correr_ronda.sh` y `correr_abierta.sh`: la ronda que corre el
  servicio se elige con una palabra en un archivo, sin tocar la unidad de
  systemd. La Prueba Abierta no añade lógica de control: es la misma ronda sin
  `parqueo.py` y con `WRO_SIN_PILARES=1`, que deja la cámara leyendo las líneas
  del piso —necesarias para contar vueltas— pero saca su color de la máquina de
  estados. En la abierta no hay pilares, así que toda detección de color es un
  falso positivo, y un falso positivo dispara una evasión contra algo que no
  existe.
- `ronda_curvas/esperar_boton.py`: el botón abre ahora la **secuencia entera** y
  no solo la carrera. Antes solo `ronda_camara.py` lo esperaba, de modo que la
  salida del estacionamiento arrancaba sola al lanzar el script. Mientras espera,
  el LED de la Pico parpadea.
- `herramientas/verificar_docs.py`: comprueba toda la documentación en busca de
  caracteres de control invisibles, enlaces e imágenes rotos, anclas internas
  muertas y finales de línea mezclados. Devuelve 1 si encuentra algo.
- `schemes/Alimentacion_y_Senales_v2.svg`: diagrama vigente de alimentación y
  señales, con las tres etapas de regulación, el reparto Pi 5 / Pico 2, el mapa
  de pines completo y el consumo real medido.
- README secciones **3.5** (línea de tiempo del proyecto y punto de inflexión),
  **4.5** (geometría de sensores, zonas ciegas y autoecos) y **7.6** (materiales
  y manufactura del chasis).
- `.gitattributes`, que fija los finales de línea en LF.

### Corregido

- **La fórmula de autonomía no renderizaba.** No era un comando LaTeX mal
  escrito sino un carácter de avance de página (0x0C) incrustado en el archivo:
  la barra invertida de la fracción se interpretó como escape al generar el
  texto y quedó como byte de control invisible. Se barrió el resto del
  repositorio buscando los demás escapes que producen lo mismo.
- **El diagrama de cableado no describía el vehículo.** Mostraba dos botones de
  selección de ronda cuando hoy hay uno solo en `GPIO 21`. Se sustituye por uno
  vigente y el original se conserva marcado como histórico.
- **El documento se contradecía sobre la versión del prototipo.** La sección 3.1
  decía que el actual era la V3 mientras la sección 0 y las seis vistas
  reglamentarias son de la V4.
- `3d-Models/` pasa a llamarse `models/`, que es el nombre de la plantilla
  oficial de la WRO. Era la única de las seis carpetas de primer nivel que no lo
  usaba.

### Medido

- **El LiDAR se ve su propia rueda** con el volante al tope, y eso bloqueaba la
  maniobra de salida del estacionamiento. Lo que lo distingue de un muro es la
  dependencia con el rumbo: un muro plano se lee $D/\sin(\text{rumbo})$ y sube al
  alejarse de los 90°, mientras que una pieza a radio fijo se lee igual en todos
  los rumbos. Medido en dos corridas: ecos planos de 61-66 mm y de 49-56 mm, con
  el radio cambiando entre ellas porque cambiaba el ángulo del volante.
- **El conteo de vueltas por líneas contaba de más.** Verificado contra la
  guiñada acumulada: 871° de giro, que son 2,4 vueltas, se contaban como tres.
  Se añadió una guiñada mínima entre cruces, porque dos líneas del mismo color
  están separadas por una esquina.
- **Flancos del chasis: 68 mm a cada costado**, medidos con regla. El modelo de
  la silueta suponía 44 y 94, y esa asimetría falsa daba holgura negativa con el
  robot parado.

### Pendiente

- Unificar las medidas del chasis entre `geometria_robot.py` (222 × 125 mm) y
  `parqueo.py` (242 × 138 mm medidos). No se toca antes de competir: cambiar el
  largo altera la geometría del parqueo, que está validada en pista con el valor
  actual.
- Validar en pista los dos arreglos de esta versión (autoeco de rueda y guiñada
  mínima entre líneas).

---

## [v0.10.0] — 2026-09-11 — Ronda completa: salir del estacionamiento, tres vueltas contadas por líneas y volver al cuadrante

Primera versión en que el vehículo ejecuta la secuencia entera de la Ronda
de Obstáculos sin intervención: sale del estacionamiento, corre esquivando
los pilares por el lado que marca su color, y para en el cuadrante del que
salió. La salida del estacionamiento se escribió como proceso aparte a
propósito, para no tocar ni una línea del código de carrera ya validado.

Commit: `0889d41` (código y manual de instalación), `e7edad6` (manual de
ensamblaje).

### Agregado
- `ronda_curvas/parqueo.py`: maniobra de salida del estacionamiento en
  vaivén, con la vigilancia por silueta completa —compara cada rumbo
  contra la chapa que hay en ESE rumbo, no contra un umbral único— y
  enderezado final contra la pared medida por el LiDAR.
- `ronda_curvas/esperar_boton.py`: puerta de arranque. El pulsador de
  `GPIO 21` abre ahora la secuencia entera y no solo la carrera; mientras
  espera, el LED de la Pico parpadea como señal visible de "cargado y
  listo". Antes la salida del estacionamiento arrancaba sola.
- `correr_completa.sh`, `wro.service` y `usar.sh`: encadenado de las dos
  fases, arranque autónomo al encender y cambio de versión entre rondas
  sin tocar los registros.
- **Conteo de vueltas por líneas de pista** en `navegacion.py`. Cada
  esquina lleva una línea naranja y una azul: cuatro de un color por
  vuelta, doce para tres. Contar tramos devuelve al robot al mismo tramo
  del que salió, propiedad que el conteo por guiñada no tiene. El yaw
  queda solo como red de seguridad, muy por encima del umbral real.
- `enlace_pico.led()` y `marcador_real.py`, el verificador independiente
  que solo cuenta un pilar como superado cuando el eje trasero cruza su
  posición con separación positiva del lado obligatorio.

### Corregido
- **El modelo del chasis estaba mal.** La silueta suponía 44 mm de
  carrocería a un costado y 94 al otro; medido con regla son **68 y 68**.
  Esa asimetría falsa daba holgura negativa con el robot parado y los doce
  primeros tiempos del vaivén cortaban al primer ciclo, avanzando uno o
  dos grados cada uno.
- **El LiDAR se veía a sí mismo.** Los cortes eran ecos planos de 49-66 mm
  en los sectores donde asoma la rueda delantera girada a tope. Se
  descartan por ser planos y por cambiar de radio con el ángulo de
  volante, que es lo que prueba que no eran un muro.
- El enderezado tenía el signo invertido respecto al vaivén y corregía
  **contra** el muro, cortándose en el primer ciclo. Y giraba a ciegas
  hasta encontrar pared: se comía 93 grados de guiñada, 22 de los 42
  segundos de la salida, y dejaba el robot mirando al revés del carril.
  Ahora, sin pared fiable a la vista, avanza recto.
- El vaivén se pasaba de vueltas (+97 grados acumulados) y sacaba el robot
  casi perpendicular al carril. Con tope de guiñada, enderezar pasa a ser
  trabajo del enderezado.
- `wro.service` tenía `Restart=always`, que relanzaba la ronda entera al
  terminar: el robot volvía a salir del estacionamiento solo, una y otra
  vez.

### Medido
Cinco corridas el 11-09, puntuadas con `marcador_real.py` y no con el
registro interno del robot:

| Corrida | Vueltas reales | Por el lado prohibido | Velocidad |
| :--- | :---: | :---: | :---: |
| 12:47 | 3 | 1 (primer pilar, a los 7,2 s) | 210 mm/s |
| 13:13 | 3 | 1 (cuarto pilar, a los 78 s) | 171 mm/s |
| 13:23 | 1,5 | **0** | 221 mm/s |
| 13:44 | 2,4 | **0** | 202 mm/s |

El fallo del primer pilar rojo, que llevaba toda la sesión, **desapareció
al arreglar la salida**: la primera medida de pared válida pasó de llegar
3,1 s después de arrancar la carrera a llegar en el primer ciclo, y los
costados al entregar el mando pasaron de 394 mm a 944 sobre un carril de
1000.

### Pendiente de validar en pista
Los dos arreglos de la sesión posterior a la última corrida: el descarte
del eco de la rueda propia y la guiñada mínima entre cruces de línea (se
verificó que 871 grados de giro, o sea 2,4 vueltas, se estaban contando
como tres).

## [v0.9.1] — 2026-09-06 a 2026-09-07 — Ronda Abierta, medidas de banco y reorganizacion

Commits representativos: `ad4e7ec`, `f566de2`, `44820da`, `8c19a03`, `bbfe582`.

### Agregado
- Ronda Abierta con el conteo de vueltas por rumbo de la IMU, y las
  herramientas de camara en vivo por HTTP y medida de las lineas de piso.
- `MEDICIONES_20260906.md`: chasis, bahia de parqueo y velocidad, todas
  remedidas con regla en vez de heredadas.

### Corregido
- La masa real de la V3 son **720 g**, no los 613 de la V2, y el margen de
  torque se rehizo con esa cifra: pasa de 2,55x a **2,18x**.
- El consumo del README era estimado por hoja de datos y con la Pi 3B. Se
  sustituye por medida real con multimetro: 1,39 A en marcha, 0,61 en
  reposo y 0,21 con la Pi apagada.
- La FSM de parqueo podia terminar en FALLO con la maniobra perfecta.
- El robot retrocedia contra los pilares que iba a rebasar.

### Reorganizado
- `ronda_cerrada` y `ronda_nueva` pasan a `legacy/`; el codigo vivo queda
  en `ronda_curvas` y `prueba_abierta`. La separacion es deliberada: lo
  archivado se conserva como registro de iteracion, pero no se despliega.

## [v0.9.0] — 2026-09-03 a 2026-09-05 — Migracion a Raspberry Pi 5

El cambio de hardware mas grande del proyecto. La Pi 3B se sustituye por
una Pi 5, y la decision es de computo medido, no de preferencia.

Commits representativos: `0b7de6c`, `840b7d1`, `f9b011f`, `e47884b`.

### Medido antes y despues
| | Pi 3B | Pi 5 |
| :--- | :---: | :---: |
| Vision por cuadro a 640x360 | 67-72 ms | **4,8 ms** |
| Vision por cuadro a 1280x720 | no cabia | **22,2 ms** |
| Edad del barrido del LiDAR | 16,0 ms de media | **0,1 ms** |

La migracion se verifico archivo a archivo: 3325 archivos identicos y los
170 CSV de telemetria coincidiendo por md5. Nada se borro de la 3B.

Eso es lo que permitio subir la camara a **1280x720 a 30 fps**. El LiDAR
dejo de tener latencia que quitar.

### Agregado
- Cerebro nuevo en `src/pi5`: homografia del suelo y vision de pista en
  milimetros, fusion camara-LiDAR de paredes y objetos, localizacion en la
  recta con mapa de doce casillas, planificador y maniobra de parqueo.
- **139 pruebas de la ronda entera que corren sin robot ni dispositivos.**
- Panel web para ver la corrida mientras ocurre, y herramientas de
  calibracion y diagnostico sobre el robot vivo.

### Corregido
- `RPi.GPIO` 0.7.1 no funciona en la Pi 5: la placa cambio al chip RP1 y
  la libreria vieja escribe directo a los registros del SoC. Se desinstala
  para que gane el shim `python3-rpi-lgpio`. Documentado en
  `INSTALACION.md` porque se vuelve a romper cada vez que alguien instala
  Adafruit-Blinka por pip.

## [v0.8.0] — 2026-08-31 a 2026-09-02 — Recorrido determinista, parqueo verificado y watchdog en la Pico

Reescritura del cerebro como `ronda_nueva`: en vez de reaccionar a lo que
aparece, recorre la pista por esquinas conocidas. Incluye la primera
maniobra de parqueo verificada y el watchdog que hace el sistema seguro
por omision.

Commits representativos: `3c96233`, `afdb163`, `b5c75e7`, `4cc12f5`,
`633b4ad`.

### Agregado
- **Watchdog autonomo de 500 ms en la Pico 2** y parser acotado de
  consignas: si la Pi se cuelga o el USB se desconecta, la Pico frena y
  centra sola en vez de seguir con la ultima orden.
- Recorrido determinista por esquinas, parqueo verificado y maniobra de
  esquina en tres tiempos calibrada con el radio de giro medido en pista.
- Ultrasonido trasero medido **por interrupcion** en la Pico, y fusion de
  esa lectura con la trasera del LiDAR para el parqueo.
- **67 pruebas offline** sin robot ni dispositivos, replay de corridas y
  despliegue del firmware de la Pico desde la propia Raspberry.

### Corregido
- El LiDAR esta a **133 mm del eje trasero, no a 162**, y va al ras del
  morro: las dos cosas medidas con regla. Los valores de montaje que se
  venian usando estaban desviados.
- Guiñada camara-LiDAR de **3,57 grados** y camara a 80 mm, calibradas
  contra pilares reales en vez de supuestas alineadas.
- El eco de la propia rueda se aleja segun cuanto gire el volante, lo que
  bloqueaba el sentido antihorario.
- El mecanismo de direccion se estaba tomando por una pared lateral.

### Validado
Tres corridas seguidas sin fallo terminal; seis esquinas y cero
emergencias tras acoplar los umbrales. Tambien se documenta lo que **no**
salio: un intento de subir la velocidad que se revirtio, y una tabla
comparativa de las cinco configuraciones probadas.

## [v0.7.3] — 2026-08-29 — Optica medida y mascara del mastil

Commits representativos: `81f5d18`, `0df7cd7`, `b9b2012`.

### Corregido
- **La optica de la camara estaba supuesta, no medida.** Se calibro con
  dos pilares reales y se dejo de rotar el cuadro, usando el sensor
  completo. El campo de vision de catalogo no es el que llega al cuadro.
- El color de un pilar dice **por que lado pasarlo**, no hacia donde
  girar. Confundir las dos cosas es lo que hacia que el robot girase hacia
  el pilar que debia esquivar.
- Se enmascara el arco que el mastil de la camara le roba al LiDAR C1.

### Agregado
- `ronda_camara`: punto de entrada e instrumentacion de la evasion, con
  cada medicion documentada **incluidas las que fallaron**.

## [v0.7.2] — 2026-08-28 — Escape frontal y desempate de esquina

Continuación directa del pendiente de v0.7.1. Caso de estudio en README
sección 8.5. El desempate se diseñó primero contra el síntoma descrito
en 8.4-3; al probarlo en pista apareció que el bucle tenía otra causa
—dos términos de control cancelándose— que es lo que arregla el escape
frontal. Ambos quedan: el escape ataca la causa medida, `GIRO_FORZADO`
es la red de abajo para el caso simétrico puro.

### Agregado
- `ronda_cerrada/navegacion.py`: nuevo estado `GIRO_FORZADO`, único con
  memoria entre ciclos. Cuenta emergencias encadenadas (cada una dentro
  de `VENTANA_ATASCO` desde la anterior); a las 4, fuerza un giro
  comprometido hacia un lado decidido una vez (última asimetría real
  memorizada entre paredes, o un lado por defecto si nunca hubo
  ninguna) y lo mantiene hasta que la esquina se abra de verdad o por
  timeout de seguridad. Pensado para el bucle del gauntlet de 8.4-3
  (133s, 51 episodios); no llegó a dispararse en la corrida de
  validación porque el escape frontal lo resolvió antes.

### Corregido
- `ronda_cerrada/navegacion.py`: **causa real del bucle**, encontrada al
  probar lo anterior en pista. Los dos términos de `_centrado_paredes`
  (posición `izq-der` y orientación `angulo_muro`) apuntan a lados
  opuestos acercándose a una esquina y se anulan: 274 de 394 ciclos con
  el frente bajo 400mm quedaban con un comando mediano de 1.5° con un
  servo que da 20-25°. El robot entraba recto contra la pared con la
  dirección centrada. Nuevo `_con_escape_frontal`: giro hacia el lado
  libre con autoridad creciente según se cierra el frente, mezclado
  sobre el centrado (no sumado, que la cancelación se lo comería).
- Criterio de racha de `GIRO_FORZADO`: el "avance neto de rumbo" no
  funcionó en pista (el robot giraba 5-7° por episodio sin escapar, así
  que la racha se reiniciaba y nunca alcanzaba el umbral). Sustituido
  por cadencia entre emergencias (`VENTANA_ATASCO=10s`), que sí separa
  atasco de incidente aislado.

### Validado
- Con motores, mismo montaje que la corrida fallida: emergencias 12→1,
  tiempo en `RETROCESO` 32%→2%, ciclos en peligro sin autoridad de
  dirección 71%→8%, rumbo recorrido 106°→442°, evasiones iniciadas 0→8.
  `GIRO_FORZADO` no llegó a dispararse (queda como red de abajo).
  Corrida cortada a los 84s a petición del equipo: falta confirmar una
  vuelta completa sin interrupción.

- `6b74f8e` feat(navegacion): forzar giro tras N retrocesos sin avance de rumbo
- `9626e80` fix(navegacion): escape frontal, el centrado se anulaba a si mismo

## [v0.7.1] — 2026-08-28 — Asistencia de esquina y límite de la reactividad pura

Caso de estudio completo en README sección 8.4. Gauntlet de 6 pilares
(el doble del reglamento) para estresar la fusión sensorial.

### Corregido
- `ronda_cerrada/navegacion.py`: emergencias en esquinas sin ningún poste
  cerca — `_centrado_paredes` no usaba `angulo_muro` (triangulación
  perp+diag ya calculada en `lidar_geometria.py`, nunca leída).
  Verificado sin motores antes de tocar la dirección; validado con
  motores en una corrida limpia: pared mínima 76mm→412mm, 5→0 emergencias.

### Agregado
- `ronda_cerrada/vision.py`: guardado opcional de frame+máscara en cada
  transición de color (`WRO_DEBUG_VISION=1`), para poder auditar un
  falso positivo de "ROJO" detectado una sola vez sin ningún pilar en
  pista, no reproducido todavía.

### Encontrado, pendiente de resolver
- Repitiendo el gauntlet completo con el arreglo activo: el robot quedó
  atrapado 133s en una esquina abordada de forma perfectamente simétrica
  (`izquierda`≈`derecha` en cada ciclo de acercamiento, `angulo_muro`
  nunca superó ±4°). Es un límite de cualquier controlador reactivo sin
  memoria entre ciclos, no un defecto del arreglo de esquina — no hay
  asimetría instantánea que triangular cuando los dos lados son
  honestamente idénticos. Necesita un mecanismo de "esta atascado, romper
  la simetría" con estado persistente entre ciclos, sin diseñar todavía.

- `71ede18` fix(navegacion): asistencia de esquina con angulo_muro, antes sin usar
- `a6358eb` feat(vision): guardar frame+mascara en cada transicion de color, opcional

## [v0.7.0] — 2026-08-27 — Reactivación de la Ronda Cerrada modular en pista

Sesión de depuración en pista de `src/pi3B/ronda_cerrada/` (la pila
modular de v0.5.0, nunca desplegada en la Pi hasta ahora) con evidencia
cuantitativa por corrida — caso de estudio completo en README sección
8.3. De un robot que no completaba una sola evasión a tres corridas
seguidas sin emergencias, esquivando el pilar rojo por la derecha y
reincorporándose al carril.

### Corregido
- `comun/enlace_pico.py`: la telemetría con sensor de color rompía el
  parseo del *heading* en silencio (la IMU quedaba clavada en 0.0).
- `ronda_cerrada/camara_driver.py`: el frame no se rotaba pese a que la
  cámara va montada invertida en el chasis.
- `ronda_cerrada/navegacion.py`: *windup* en `_centrado_paredes` sin
  recorte al servo; timeouts de evasión más cortos que la física real;
  salida de `RETROCESO` que no comprobaba si el peligro ya se había
  despejado; `SOBREPASO`/`REINCORPORACION` corrigiendo por rumbo en vez
  de por posición (podían cumplir el objetivo entero y acabar contra un
  muro); `DIST_SOBREPASO_MM` dimensionado por el poste cuando en la
  práctica lo limita la pared.
- `ronda_cerrada/tracker.py`: `MM_POR_SEG_A_PWM100` sobreestimaba 2.3
  veces la velocidad real (medida en pista: curva PWM→velocidad).
- Hardware: regulador XL4015/4016 entregando 4.9V, la Raspberry en bajo
  voltaje activo incluso en reposo (`vcgencmd get_throttled` = `0x50005`
  → `0x50000` tras reajustar el trimpot a 5.132V).

### Agregado
- `comun/registro_metricas.py`: percepción cruda por ciclo (`frontal`,
  `izquierda`, `derecha`, `trasera`, `color_cam`, estado del tracker),
  necesaria para diagnosticar de dónde sale cada error en vez de solo el
  error ya derivado.
- `src/pico/main.py`: sincronizado con el sensor de color TCS3472 (que
  ya estaba flasheado en el Pico físico pero nunca se había commiteado)
  y con el campo opcional `kd` de la consigna serial (que la versión
  flasheada había perdido al agregar el sensor).
- README secciones 5.3-C (estado real del sentido de carrera: hardware
  instalado, telemetría parseada, no consumido por `navegacion.py` — y
  por qué eso es un diseño deliberado, no una omisión) y 8.3 (caso de
  estudio completo con evidencia por corrida).

- `c84f387` fix(comun): parsear la telemetria de la Pico con sensor de color
- `268c633` fix(ronda_cerrada): enderezar el frame, la camara va montada invertida
- `528aef5` feat(metricas): registrar percepcion cruda por ciclo, no solo el error
- `ad74c17` fix(navegacion): recortar el centrado al servo, elimina el windup
- `e78884f` fix(navegacion): derivar los timeouts de evasion de la velocidad real
- `9e857da` fix(navegacion): terminar el retroceso al despejarse, no por reloj
- `cb4f710` refactor(navegacion): salir de la evasion por posicion, no por rumbo
- `12ca0f1` fix(tracker): medir la velocidad real, el modelo sobreestimaba 2.3 veces
- `e5999af` fix(navegacion): acortar SOBREPASO, lo limita la pared y no el poste
- `c8219c1` feat(pico): sincronizar el firmware con el sensor de color TCS3472

## [v0.6.0] — 2026-07-27 — Métricas cuantitativas de rendimiento

### Agregado
- `src/pi3B/comun/registro_metricas.py`: logger CSV de telemetría por
  ciclo (fase, estado, heading, error lateral, ángulo, velocidad),
  integrado en `ronda_abierta.py` y `ronda_cerrada.py`.
- `src/pi3B/calibracion/analizar_log.py`: resume los CSV de
  `registro_metricas.py` en métricas agregadas (error lateral
  promedio/máximo, saturación del servo, eventos de emergencia) para
  validar el ajuste de `KP_LATERAL`/`KD_ESTABILIDAD` con datos en vez de
  observación cualitativa (README sección 5.4).
- Este `CHANGELOG.md`.

- `26badf2` feat(pi3B): instrumentar métricas cuantitativas de rendimiento en pista

## [v0.5.0] — 2026-07-21 a 2026-07-24 — Navegación modular y reorganización

Reescritura de la máquina de estados de evasión de la Ronda Cerrada como
lógica pura sin I/O, y reorganización de `src/pi3B/` en carpetas por rol
(`comun/`, `ronda_abierta/`, `ronda_cerrada/`, `calibracion/`).

- `88698f0` feat(close): reescritura modular de la navegación de la Ronda Cerrada
- `9aafb59` chore(pi3B): organizar src/pi3B en carpetas por rol
- `7cee7f2` experimento(pi3B): separar driver/procesador en lidar y cámara
- `2f87433` experimento(pi3B): unificar drivers de LiDAR/Pico entre las dos rondas
- `2b88cec` feat(pi3B): agregar deploy.sh y documentar clonar+desplegar en la Pi
- `4b8a06e` fix(ronda_cerrada): retroceso reactivo con perfil LiDAR de 360 grados
- `4e67679` fix(ronda_cerrada): la evasión ahora ve las paredes

## [v0.4.0] — 2026-07-07 a 2026-07-21 — Ronda Cerrada: visión, tracker y depuración en pista

Primera implementación funcional de la Ronda Cerrada (evasión de postes
rojo/verde) con calibración HSV dedicada, tracker LiDAR y el caso de
estudio de depuración documentado en README sección 8.2.

- `248d83e` Códigos de calibración HSV para la ronda cerrada
- `140f553` fix(close_round): corregir lado de evasión invertido y espacio de color de la cámara
- `6c9158f` feat(close_round): usar control proporcional con tracker LiDAR en la evasión
- `5a182d9` fix(close_round): subir el timeout de confirmación DETECTADO->ESQUIVANDO de 0.3s a 1.2s
- `6602a07` fix(close_round): dar más tiempo/ángulo a RECENTRANDO para converger
- `0c559a1` fix: implementar modo Inercial real (sostener última pared válida)
- `f23a8b7` refactor(close_round): dividir Close2_round.py en módulos por responsabilidad
- `3144a3f` docs: agregar manual de instalación (INSTALACION.md)

## [v0.3.0] — 2026-07-03 a 2026-07-05 — Chasis de producción V2 (LEGO, 613 g)

Migración del chasis monocasco impreso en 3D (V1, ~800 g) a la
plataforma LEGO Technic de producción (V2, 613 g exactos). Incluye la
corrección del centro de dirección del servo (probado en 180°, revertido
a 90° tras validación en pista).

- `07cea89` Estructura base y hardware V2 en LEGO
- `4afdab4` justificar ventajas cinemáticas del chasis LEGO de 613g frente a impresión 3D
- `ca1ea85` actualizar README principal con peso de 613g, regulador XL4016 y análisis de torque
- `5e917e1` implementar matriz fotográfica comparativa de 6 ejes para V1 y V2
- `305e46c` Arreglo de ángulo central del robot de 90 a 180 grados
- `dc4f532` Arreglo en equivocación de ángulo central (revertido a 90°)

## [v0.2.0] — 2026-06-18 — Migración a Raspberry Pi 3B

Cambio de la capa de percepción de alto nivel de Raspberry Pi 5 a
Raspberry Pi 3B (hardware disponible al equipo).

- `bf474b5` Arreglo prueba de RPlidar, cambio de Raspberry Pi de 5 a 3B

## [v0.1.0] — 2026-01-06 a 2026-06-10 — Estructura inicial y control serial

Esqueleto reglamentario del repositorio (`src/`, `v-photos/`, `schemes/`,
etc.) y primera versión funcional del protocolo serial Pi↔Pico: máquina
de estados base en la Pico 2 y parser no bloqueante para el LiDAR.

- `07a7bc6` chore: crear estructura de carpetas oficiales para WRO 2026
- `1a6b984` feat(pico2): script nativo en MicroPython para control de actuadores por serial
- `d84f8be` feat(control): implementar máquina de estados base y bucle de telemetría
- `99b7c0f` feat(pico): implementar parser serial no bloqueante para lectura de zonas del lidar
- `99b052e` feat(pico): corregir mapeo de pines I2C de la IMU y habilitar telemetría

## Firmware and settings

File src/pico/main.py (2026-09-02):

import sys
import select
from machine import Pin, I2C, PWM
import time

from protocolo_seguro import parsear_consigna, watchdog_vencido

# El ultrasonido es una ayuda, no un requisito de seguridad: si el modulo no
# se copio a la Pico el robot tiene que seguir corriendo la ronda. Se anuncia
# la ausencia por telemetria (US:-1), que es la senal que la Pi ya sabe leer.
try:
    from ultrasonido import SIN_MEDIDA, FiltroUltrasonido
except ImportError:
    SIN_MEDIDA = -1
    FiltroUltrasonido = None

# Configurar el Poller para lectura serial asincrona desde la Pi 3B
poller = select.poll()
poller.register(sys.stdin, select.POLLIN)

# --- CONFIGURACION DE BUSES I2C INDEPENDIENTES ---
# Bus 0: IMU MPU6050 en GP16 (SDA) y GP17 (SCL)
i2c_imu = I2C(0, sda=Pin(16), scl=Pin(17), freq=400000)

# Bus 1: Sensor de color TCS3472 en GP18 (SDA) y GP19 (SCL). Lee la linea
# del piso para el sentido de carrera (AZUL/NARANJA, ver TCS3472 abajo).
i2c_tcs = I2C(1, sda=Pin(18), scl=Pin(19), freq=100000)

# --- HARDWARE DE CONTROL (SERVO Y MOTOR) ---
servo = PWM(Pin(12))
servo.freq(50)

# Controlador de Motores TB6612FNG
stby = Pin(28, Pin.OUT)
bin2 = Pin(26, Pin.OUT)
bin1 = Pin(27, Pin.OUT)
pwmb = PWM(Pin(22))
pwmb.freq(2000)

stby.value(1)

# --- ULTRASONIDO TRASERO (HC-SR04 / US-100) ---
# Trigger en GP14, Echo en GP15. Van libres: GP12 es el servo, GP16-GP19 los
# dos buses I2C, GP22 el PWM del motor y GP26-GP28 el TB6612FNG.
#
# AVISO DE CABLEADO: el Echo del HC-SR04 sale a 5 V y los GPIO de la Pico NO
# toleran 5 V. Hay que bajarlo con un divisor (1 k en serie desde Echo y 2 k
# a GND da 3,3 V) o usar un US-100 alimentado a 3,3 V. Sin eso se dana la
# entrada de la Pico.
#
# POR QUE NO SE USA machine.time_pulse_us: esa llamada bloquea hasta que
# vuelve el eco, hasta 30 ms con el timeout tipico. Este bucle corre cada
# 5 ms y es el que sostiene el servo, el motor y el watchdog de comandos:
# pararlo 30 ms de cada 60 seria peor que no tener sensor. En su lugar se
# lanza el pulso y se cronometra el flanco del eco por interrupcion, de modo
# que el control sigue corriendo mientras el sonido viaja.
US_PIN_TRIGGER = 14
US_PIN_ECHO = 15
US_PERIODO_MS = 60      # el HC-SR04 pide >=60 ms entre disparos (ecos fantasma)
US_ESPERA_MAX_MS = 40   # sin eco en este plazo se da el disparo por perdido
US_MINIMA_MM = 20       # por debajo de su zona muerta la lectura no significa nada
US_MAXIMA_MM = 4000


class SensorUltrasonido:
    """Disparo periodico y medida del eco por interrupcion, sin bloquear."""

    def __init__(self, pin_trigger, pin_echo, filtro):
        self._trigger = Pin(pin_trigger, Pin.OUT, value=0)
        self._echo = Pin(pin_echo, Pin.IN)
        self._filtro = filtro
        self._ancho_us = 0
        self._t_subida = 0
        self._midiendo = False
        self._listo = False
        self._esperando = False
        self._t_disparo = time.ticks_ms()
        self.distancia_mm = SIN_MEDIDA
        self._echo.irq(
            handler=self._al_flanco,
            trigger=Pin.IRQ_RISING | Pin.IRQ_FALLING,
        )

    def _al_flanco(self, pin):
        # Rutina de interrupcion: solo enteros y booleanos sobre atributos que
        # ya existen. Nada que reserve memoria (ni floats, ni listas, ni
        # formateo), porque en MicroPython eso puede fallar dentro de una ISR.
        if pin.value():
            self._t_subida = time.ticks_us()
            self._midiendo = True
        elif self._midiendo:
            self._ancho_us = time.ticks_diff(time.ticks_us(), self._t_subida)
            self._midiendo = False
            self._listo = True

    def _disparar(self, ahora_ms):
        self._t_disparo = ahora_ms
        self._esperando = True
        self._midiendo = False
        self._trigger.value(0)
        time.sleep_us(2)
        self._trigger.value(1)
        time.sleep_us(10)       # el unico bloqueo: 10 us, no 30 ms
        self._trigger.value(0)

    def actualizar(self, ahora_ms):
        """Se llama en cada vuelta del bucle; devuelve la distancia vigente."""

        if self._listo:
            self._listo = False
            self._esperando = False
            self.distancia_mm = self._filtro.actualizar(self._ancho_us)
        elif self._esperando and time.ticks_diff(
            ahora_ms, self._t_disparo
        ) > US_ESPERA_MAX_MS:
            # Sin eco: pared oblicua, fuera de alcance o sensor desconectado.
            # Cuenta como fallo para que la medida caduque en vez de quedarse
            # congelada en el ultimo valor bueno.
            self._esperando = False
            self.distancia_mm = self._filtro.actualizar(0)

        if not self._esperando and time.ticks_diff(
            ahora_ms, self._t_disparo
        ) >= US_PERIODO_MS:
            self._disparar(ahora_ms)
        return self.distancia_mm

    def apagar(self):
        """Desarma la interrupcion y deja el trigger en reposo."""

        self._echo.irq(handler=None)
        self._trigger.value(0)
        self._esperando = False
        self._midiendo = False


# Limites de giro del servo calibrados
CENTRO = 90
LIMITE_DER = 70    # Maximo giro a la derecha
LIMITE_IZQ = 115   # Maximo giro a la izquierda

def mover_servo(angulo):
    # Limita al rango calibrado en vez de 0-180 (protege el servo)
    angulo = max(LIMITE_DER, min(LIMITE_IZQ, angulo))
    duty = int(1638 + (angulo / 180.0) * (8192 - 1638))
    servo.duty_u16(duty)

def controlar_motor(velocidad_porcentaje):
    if velocidad_porcentaje > 0:
        bin1.value(1)
        bin2.value(0)
        vel = max(0, min(100, velocidad_porcentaje))
    elif velocidad_porcentaje < 0:
        bin1.value(0)
        bin2.value(1)
        vel = max(0, min(100, abs(velocidad_porcentaje)))
    else:
        bin1.value(1)
        bin2.value(1)
        vel = 0

    duty_u16 = int((vel / 100.0) * 65535)
    pwmb.duty_u16(duty_u16)

class MPU6050:
    def __init__(self, i2c_bus, addr=0x68):
        self.i2c = i2c_bus
        self.addr = addr
        self.i2c.writeto_mem(self.addr, 0x6B, b'\x00') # Activar sensor
        # Configura el giroscopio a +-2000 grados/s para evitar saturacion
        self.i2c.writeto_mem(self.addr, 0x1B, b'\x18')

    def get_gyro_z(self):
        data = self.i2c.readfrom_mem(self.addr, 0x47, 2)
        val = (data[0] << 8) | data[1]
        if val >= 32768: val -= 65536
        return val / 16.4 # Factor de escala para +-2000 grados/s

# --- SENSOR DE COLOR DE PISO (TCS3472), CON CALIBRACION DINAMICA EN HSV ---
# Lee la linea de color del piso una vez por vuelta al arranque para fijar
# el sentido de carrera (AZUL=Antihorario, NARANJA=Horario segun la
# convencion del equipo). No hay libreria oficial para MicroPython: se
# escribe/lee directo sobre los registros del chip por I2C.
class TCS3472:
    def __init__(self, i2c_bus, addr=0x29):
        self.i2c = i2c_bus
        self.addr = addr
        self.escribir(0x00, 0x01)       # PON (Power On)
        time.sleep_ms(10)
        self.escribir(0x00, 0x03)       # PON + AEN (Activar lectura RGBC)
        self.escribir(0x01, 0xF6)       # Integration time 24ms
        self.escribir(0x0F, 0x02)       # Ganancia 16x

        self.historial_h = []
        self.historial_s = []
        self.tamano_ventana = 4
        self.saturacion_base_pista = 0.20

    def escribir(self, reg, valor):
        self.i2c.writeto(self.addr, bytearray([0x80 | reg, valor]))

    def leer_16(self, reg):
        self.i2c.writeto(self.addr, bytearray([0x80 | 0x20 | reg]), False)
        datos = self.i2c.readfrom(self.addr, 2)
        return datos[0] | (datos[1] << 8)

    def calibrar_suelo_inicial(self):
        # Se llama una vez al arrancar: promedia la saturacion del piso
        # blanco bajo la iluminacion real de la pista para fijar el
        # umbral que distingue "pista" de "linea de color", en vez de un
        # valor fijo que se desajusta con cada cambio de luz.
        muestras_s = []
        for _ in range(25):
            try:
                c = self.leer_16(0x14)
                r = self.leer_16(0x16)
                g = self.leer_16(0x18)
                b = self.leer_16(0x1A)
                if c > 0:
                    max_c = max(r, g, b)
                    min_c = min(r, g, b)
                    df = max_c - min_c
                    s = 0.0 if max_c == 0 else df / max_c
                    muestras_s.append(s)
            except:
                pass
            time.sleep_ms(10)

        if muestras_s:
            # Asigna umbral de saturacion de pista con margen de tolerancia
            self.saturacion_base_pista = (sum(muestras_s) / len(muestras_s)) + 0.12

    def obtener_color(self):
        try:
            c = self.leer_16(0x14)
            r = self.leer_16(0x16)
            g = self.leer_16(0x18)
            b = self.leer_16(0x1A)

            if c < 40:
                return "NINGUNO"

            # Conversion de RGB a espacio HSV (Hue, Saturation, Value)
            max_c = max(r, g, b)
            min_c = min(r, g, b)
            df = max_c - min_c

            s = 0.0 if max_c == 0 else df / max_c

            if df == 0:
                h = 0.0
            elif max_c == r:
                h = (60 * ((g - b) / df) + 360) % 360
            elif max_c == g:
                h = (60 * ((b - r) / df) + 120) % 360
            elif max_c == b:
                h = (60 * ((r - g) / df) + 240) % 360

            # Filtro de promedio movil para mitigar ruido y destellos
            self.historial_h.append(h)
            self.historial_s.append(s)

            if len(self.historial_h) > self.tamano_ventana:
                self.historial_h.pop(0)
                self.historial_s.pop(0)

            h_prom = sum(self.historial_h) / len(self.historial_h)
            s_prom = sum(self.historial_s) / len(self.historial_s)

            # Descarte dinamico de pista por umbral de saturacion
            if s_prom < self.saturacion_base_pista:
                return "PISTA"

            # Evaluacion del tono (Hue) con tolerancias de movimiento
            if 5 <= h_prom <= 42:
                return "NARANJA"
            elif 180 <= h_prom <= 245:
                return "AZUL"
            else:
                return "PISTA"

        except:
            return "ERROR"

try:
    sensor_imu = MPU6050(i2c_imu)
    sensor_color = TCS3472(i2c_tcs)
    mover_servo(CENTRO) # Arranca alineado al centro calibrado
    controlar_motor(0)
except Exception as e:
    pass

# El ultrasonido se monta aparte: si no esta cableado o falta el modulo, el
# resto del firmware arranca igual y la trama sale con US:-1.
sensor_ultrasonido = None
if FiltroUltrasonido is not None:
    try:
        sensor_ultrasonido = SensorUltrasonido(
            US_PIN_TRIGGER,
            US_PIN_ECHO,
            FiltroUltrasonido(
                ventana=3, minima_mm=US_MINIMA_MM, maxima_mm=US_MAXIMA_MM
            ),
        )
    except Exception:
        sensor_ultrasonido = None

# Calibracion del giroscopio
giro_z_offset = 0.0
for _ in range(100):
    try:
        giro_z_offset += sensor_imu.get_gyro_z()
    except: pass
    time.sleep(0.01)
giro_z_offset /= 100.0

# Calibracion de saturacion base del suelo (piso blanco bajo la luz real)
try:
    sensor_color.calibrar_suelo_inicial()
except:
    pass

angulo_acumulado = 0.0
angulo_objetivo = 0.0
velocidad_comandada = 0
color_detectado = "PISTA"
distancia_ultrasonido = SIN_MEDIDA

# Constante de Amortiguacion: Evita que el coche devane o curve de golpe
KD_ESTABILIDAD = 0.12

# Interruptor de la amortiguacion, controlado por un tercer campo opcional
# en la consigna ("velocidad,angulo" sigue funcionando igual y deja esto en
# 1.0). Actualmente ningun script de carrera lo usa: solo tiene sentido al
# medir el radio de giro real -- en un giro sostenido la velocidad angular
# es constante y no nula, asi que el termino KD desvia el servo varios
# grados del angulo comandado, y con la amortiguacion activa el radio de
# giro que se mida NO corresponde al comando que se mando.
kd_activo = 1.0

# Si la Pi deja de enviar consignas validas (cable USB desconectado, proceso
# caido o trama corrupta), la Pico frena y centra por si sola. El timeout es
# holgado frente al ciclo LiDAR normal y no depende del watchdog de Linux.
WATCHDOG_COMANDO_MS = 500
ultimo_comando_valido = None
watchdog_activo = True

ultima_lectura = time.ticks_ms()
ultimo_envio_telemetria = time.ticks_ms()

# Bucle principal de control
while True:
    try:
        tiempo_actual = time.ticks_ms()
        dt = time.ticks_diff(tiempo_actual, ultima_lectura) / 1000.0
        ultima_lectura = tiempo_actual

        # 1. Integracion de angulo con IMU
        try:
            velocidad_z = sensor_imu.get_gyro_z() - giro_z_offset
        except:
            velocidad_z = 0.0

        if abs(velocidad_z) > 0.15:
            angulo_acumulado += velocidad_z * dt

        # 2. Lectura del sensor de color (TCS3472 con filtro HSV)
        color_detectado = sensor_color.obtener_color()

        # 2b. Ultrasonido trasero. No bloquea: dispara como mucho una vez cada
        # US_PERIODO_MS y recoge lo que la interrupcion haya dejado listo.
        if sensor_ultrasonido is not None:
            try:
                distancia_ultrasonido = sensor_ultrasonido.actualizar(tiempo_actual)
            except:
                distancia_ultrasonido = SIN_MEDIDA

        # 3. Lectura de comandos desde la Pi 3B
        if poller.poll(0):
            linea = sys.stdin.readline().strip()
            if linea:
                consigna = parsear_consigna(linea)
                if consigna is not None:
                    velocidad_comandada, angulo_objetivo, kd_activo = consigna
                    ultimo_comando_valido = tiempo_actual
                    watchdog_activo = False

        if watchdog_vencido(
            tiempo_actual,
            ultimo_comando_valido,
            WATCHDOG_COMANDO_MS,
            time.ticks_diff,
        ):
            velocidad_comandada = 0
            angulo_objetivo = 0.0
            kd_activo = 1.0
            watchdog_activo = True

        # 4. Angulo objetivo (de la Pi) sobre el centro, con amortiguacion por gyro
        angulo_servo = CENTRO + angulo_objetivo - (velocidad_z * KD_ESTABILIDAD * kd_activo)
        angulo_servo = max(LIMITE_DER, min(LIMITE_IZQ, angulo_servo))
        mover_servo(angulo_servo)

        # 5. Ajustar velocidad de motores
        if velocidad_comandada == 0:
            controlar_motor(0)
        else:
            controlar_motor(velocidad_comandada)

        # 6. Telemetria a la Pi 3B: angulo, color de piso y ultrasonido.
        # El campo US va antes de WD para no alterar el orden que ya leia el
        # firmware anterior; los parsers de la Pi recorren campos por nombre,
        # asi que anadirlo no rompe a quien no lo espera.
        if time.ticks_diff(tiempo_actual, ultimo_envio_telemetria) > 50:
            estado_watchdog = "STOP" if watchdog_activo else "OK"
            sys.stdout.write(
                f"IMU:{angulo_acumulado:.2f},COLOR:{color_detectado},"
                f"US:{distancia_ultrasonido},WD:{estado_watchdog}\n"
            )
            ultimo_envio_telemetria = tiempo_actual

        time.sleep(0.005)

    except KeyboardInterrupt:
        controlar_motor(0)
        stby.value(0)
        mover_servo(CENTRO)
        # Desarmar el eco: si no, la interrupcion sigue viva despues de que
        # el bucle termine y dispara sobre un objeto que ya nadie consulta.
        if sensor_ultrasonido is not None:
            try:
                sensor_ultrasonido.apagar()
            except:
                pass
        break

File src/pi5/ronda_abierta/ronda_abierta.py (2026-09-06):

"""Ronda Abierta (Open Challenge) para la Pi 5.

Tres vueltas siguiendo las paredes y parada dentro de la seccion de salida.
Sin pilares, sin camara y sin mapa: la Ronda Abierta no los necesita, y
mantenerlo en un solo archivo auditable es una virtud, no un descuido.

PORTADO DESDE `src/pi3B/ronda_abierta/ronda_abierta.py`. Tres cosas cambian, y
ninguna es opcional:

1. **El conteo de vueltas ya no puede salir del sensor de color de piso.** En
   este robot la Pico responde ``COLOR:SIN_SENSOR``: el TCS3472 no esta
   montado. Ese sensor era quien contaba las doce lineas naranjas, o sea todo
   el criterio de "ya son tres vueltas". Aqui las esquinas se cuentan por el
   rumbo acumulado de la IMU, que la Pico ya publica y que en esta placa
   deriva -0,00 deg/s medidos. Si algun dia vuelve el sensor, el contador por
   color sigue implementado y se activa solo.

2. **El LiDAR se lee por bloques**, reutilizando ``comun.lidar_driver``. El
   original hacia read(1)+read(4) por muestra; medido en la Pi con carga, esa
   lectura se queda atras y entrega barridos viejos.

3. **Se enmascara la estructura del propio robot.** El mastil y su soporte
   devuelven eco permanente en 28..54 y 141..212 grados, y el primero cae
   DENTRO del sector derecho (30-90): sin enmascararlo, la distancia derecha
   se queda clavada en ~142 mm y el centrado entre paredes deja de funcionar.

Uso tipico::

    python3 -m ronda_abierta.ronda_abierta --arranque-inmediato --velocidad 45
"""

import argparse
import math
import signal
import sys
import threading
import time
from typing import Dict, Iterable, List, Optional, Sequence, Tuple


# --- Puertos y enlace ----------------------------------------------------
PUERTO_LIDAR = "/dev/ttyUSB0"
PUERTO_PICO = "/dev/ttyACM0"
BAUDRATE_LIDAR = 460800
BAUDRATE_PICO = 115200
PIN_BOTON = 21

# --- Navegacion ----------------------------------------------------------
KP_LATERAL = 0.14
VELOCIDAD_CRUCERO = 90          # valor heredado de la 3B; ver --velocidad
VELOCIDAD_META = 55
ANGULO_MAX_DEG = 25.0           # el firmware acota igual, pero no se le pide de mas

# --- Fin de ronda --------------------------------------------------------
VUELTAS_OBJETIVO = 3
ESQUINAS_POR_VUELTA = 4
GRADOS_POR_ESQUINA = 90.0
# Margen en grados que se le regala al contador. Va a CERO a proposito:
#
# - Exigir de mas (n*90 + margen) es un fallo grave, no una precaucion: tras
#   la ultima esquina el robot enfila la recta final y deja de girar, asi que
#   esos grados de mas no llegan nunca y la ronda no terminaria.
# - Exigir de menos tampoco hace falta. El contador es monotono y el bamboleo
#   del centrado oscila alrededor de un valor fijo en vez de acumular (la
#   Pico integra el giroscopio con zona muerta), asi que no puede inventar
#   una esquina: como mucho la cuenta un par de grados antes de rematarla.
#
# Queda como parametro por si la pista dice otra cosa, no porque hoy sirva.
MARGEN_ESQUINA_DEG = 0.0
TIEMPO_AVANCE_META_S = 1.8      # avance final dentro de la seccion de salida
TOLERANCIA_FIRMA_MM = 80.0      # parecido a la firma geometrica de la salida

# --- Sectores del LiDAR --------------------------------------------------
SECTOR_DERECHA = (30.0, 90.0)
SECTOR_IZQUIERDA = (270.0, 330.0)

# Arcos con eco permanente de la propia estructura, MEDIDOS con
# `herramientas/diag_mastil.py` el 2026-09-05: 28..54 grados a 142-172 mm
# (soporte) y 141..212 a 35-68 mm (mastil). Se remide cada vez que se toca el
# montaje de la camara: la mascara es del MONTAJE, no del robot.
SECTORES_CIEGOS = ((27.0, 55.0), (140.0, 213.0))

DISTANCIA_MAX_MM = 6000.0
SIN_DATO_MM = 8000.0
# Un sector sin ningun eco no es "camino libre". Se sustituye por este valor
# solo para poder seguir centrando; nunca autoriza nada.
FALLBACK_LATERAL_MM = 2000.0


# =========================================================================
# Logica pura (probada sin hardware en tests/)
# =========================================================================

def en_sector(angulo: float, sector: Tuple[float, float]) -> bool:
    """Pertenencia a un sector angular, soportando el cruce por 0 grados."""

    inicio, fin = sector
    angulo %= 360.0
    inicio %= 360.0
    fin %= 360.0
    if inicio <= fin:
        return inicio <= angulo <= fin
    return angulo >= inicio or angulo <= fin


def esta_ciego(angulo: float, ciegos: Iterable[Tuple[float, float]]) -> bool:
    return any(en_sector(angulo, sector) for sector in ciegos)


def minimos_laterales(
    barrido: Sequence[Tuple[float, float]],
    ciegos: Iterable[Tuple[float, float]] = SECTORES_CIEGOS,
    sector_derecha: Tuple[float, float] = SECTOR_DERECHA,
    sector_izquierda: Tuple[float, float] = SECTOR_IZQUIERDA,
) -> Tuple[float, float]:
    """Distancia minima a cada lado, ignorando la estructura del robot.

    Devuelve ``(izquierda_mm, derecha_mm)``. Un lado sin ecos utiles devuelve
    ``inf``; quien llama decide que hacer con eso.
    """

    izquierda = math.inf
    derecha = math.inf
    for angulo, distancia in barrido:
        if not (0.0 < distancia < DISTANCIA_MAX_MM):
            continue
        if esta_ciego(angulo, ciegos):
            continue
        if en_sector(angulo, sector_derecha):
            if distancia < derecha:
                derecha = distancia
        elif en_sector(angulo, sector_izquierda):
            if distancia < izquierda:
                izquierda = distancia
    return izquierda, derecha
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

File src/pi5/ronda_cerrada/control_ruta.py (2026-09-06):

"""Control de ruta puro y ligero para ``ronda_nueva``.

La clase de este modulo no abre puertos, no crea hilos y no depende de
OpenCV. Recibe la geometria ya filtrada y los tracks fusionados, y devuelve
una :class:`~src.pi5.ronda_cerrada.modelos.Consigna` por barrido. Esto permite
usar exactamente la misma FSM en la Pi 3B y en los replays de escritorio.

Convenciones importantes:

* ``sentido`` vale ``+1`` para pista antihoraria/giros a la izquierda y
  ``-1`` para pista horaria/giros a la derecha.
* el servo es positivo hacia la izquierda;
* un pilar verde se pasa por su izquierda y uno rojo por su derecha;
* un timeout siempre termina en ``FAILED``. Nunca sustituye una transicion
  geometrica ni una verificacion de estacionamiento.
"""

import inspect
import math
import time
from typing import Any, Dict, Optional, Sequence

from .estacionamiento import ControlEstacionamiento, ejecutar_estacionamiento
from .modelos import (
    Consigna,
    Corredor,
    HuecoParqueo,
    MedidasParqueo,
    TrackObstaculo,
)


def _limitar(valor: float, minimo: float, maximo: float) -> float:
    return max(minimo, min(maximo, valor))


def _diferencia_angular(actual: float, referencia: float) -> float:
    """Diferencia firmada, incluso si el IMU cruza +/-180 grados."""

    return (float(actual) - float(referencia) + 180.0) % 360.0 - 180.0


def _finito_no_negativo(valor: float) -> bool:
    try:
        return math.isfinite(float(valor)) and float(valor) >= 0.0
    except (TypeError, ValueError):
        return False


def _distancia_lidar_real(valor: float, sin_dato_mm: float) -> bool:
    """Rechaza NaN, cero y el centinela que representa ausencia de eco."""

    return bool(
        _finito_no_negativo(valor)
        and 0.0 < float(valor) < float(sin_dato_mm)
    )


def _cobertura_suficiente(valor: float, minimo: float) -> bool:
    try:
        cobertura = float(valor)
    except (TypeError, ValueError):
        return False
    return bool(math.isfinite(cobertura) and minimo <= cobertura <= 1.0)


class ControlRuta:
    """FSM de carrera, evasion, recuperacion, giros y estacionamiento."""

    ESTADOS = (
        "WAIT_DIRECTION",
        "CRUISE",
        "AVOID_APPROACH",
        "AVOID_PASS",
        "RECENTER",
        "TURN",
        "RECOVERY",
        "FORCED_TURN",
        "PARKING",
        "DONE",
        "FAILED",
    )

    def __init__(self, config: Dict[str, Any]):
        self._config = config
        self._control = config["control"]
        self._parking_cfg = config["parking"]

        self._angulo_izquierda = float(
            self._control["steering_max_left_deg"]
        )
        self._angulo_derecha = float(
            self._control["steering_max_right_deg"]
        )
        self._estacionamiento = ControlEstacionamiento(config)
        # La FSM de estacionamiento puede evolucionar sin romper este modulo.
        # Se inspecciona una sola vez (no en el bucle de control de la Pi).
        self._parametros_estacionamiento = set(
            inspect.signature(self._estacionamiento.procesar).parameters
        )
        self.reiniciar()

    def reiniciar(self) -> None:
        self._estado = "WAIT_DIRECTION"
        self._esquinas = 0
        direccion = str(self._control["turn_direction"]).strip().upper()
        self._sentido = 1 if direccion == "LEFT" else -1 if direccion == "RIGHT" else 0
        self._lado_parqueo_solicitado = 0
        self._t_inicio: Optional[float] = None
        self._t_estado: Optional[float] = None

        self._error_lateral_filtrado: Optional[float] = None
        self._error_rumbo_filtrado: Optional[float] = None
        self._heading_actual = 0.0
        self._ultrasonido_mm: Optional[float] = None
        self._heading_referencia: Optional[float] = None
        self._confirmaciones_esquina = 0
        self._confirmaciones_salida_esquina = 0
        self._t_ultima_esquina = -math.inf
        self._heading_inicio_giro = 0.0
        self._kturn_fase = "AVANCE"
        self._kturn_tramos = 0
        self._t_kturn_fase: Optional[float] = None

        self._track_id: Optional[int] = None
        self._track_color: Optional[str] = None
        self._ultimo_track: Optional[TrackObstaculo] = None
        self._track_observado = False
        self._heading_sobrepaso = 0.0
        self._t_track_perdido: Optional[float] = None
        self._color_heredado = False
        self._distancia_sobrepaso_mm = 0.0
        self._t_ultimo_sobrepaso: Optional[float] = None
        self._confirmaciones_recentrado = 0

        self._recuperaciones = []
        self._forzar_al_salir = False
        self._heading_inicio_forzado = 0.0
        self._signo_giro_forzado = 0
        self._lado_emergencia = 0
        self._confirmaciones_recuperacion_despejada = 0

        self._ultimo_angulo = 0.0
        self._ultima_velocidad = 0
        self._razon_terminal = ""
        self._estacionamiento.reiniciar()

    @property
    def estado(self) -> str:
        return self._estado

    @property
    def esquinas(self) -> int:
        return self._esquinas

    @property
    def sentido(self) -> int:
        return self._sentido

    @property
    def lado_parqueo_solicitado(self) -> int:
        """Lado pedido a percepcion: 0 hasta completar las esquinas."""

        return self._lado_parqueo_solicitado

    @property
    def track_activo(self) -> Optional[TrackObstaculo]:
        """Ultima observacion del pilar unido a la maniobra actual."""

        return self._ultimo_track

    @property
    def track_activo_id(self) -> Optional[int]:
        return self._track_id

    @property
    def track_activo_color(self) -> Optional[str]:
        return self._track_color

    @property
    def track_activo_observado(self) -> bool:
        """Indica si el track activo fue observado en el ciclo actual."""

        return self._track_observado

    @property
    def distancia_sobrepaso_mm(self) -> float:
        return self._distancia_sobrepaso_mm

    def _entrar(self, estado: str, ahora: float) -> None:
        if estado not in self.ESTADOS:
            raise ValueError("estado desconocido: " + estado)
        self._estado = estado
        self._t_estado = float(ahora)

    def _tiempo_estado(self, ahora: float) -> float:
        if self._t_estado is None:
            return 0.0
        return max(0.0, float(ahora) - self._t_estado)

    def _acotar_angulo(self, angulo: float) -> float:
        return _limitar(
            float(angulo), self._angulo_derecha, self._angulo_izquierda
        )

    def _emitir(
        self,
        velocidad: float,
        angulo: float,
        razon: str = "",
        terminado: bool = False,
        verificado: bool = False,
        detener_inmediato: bool = False,
        direccion_neutra: bool = False,
        slew_angulo_deg: Optional[float] = None,
    ) -> Consigna:
        """Aplica limites fisicos y slew en el unico punto de salida."""
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

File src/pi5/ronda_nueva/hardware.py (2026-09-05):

"""Drivers exclusivos de la ronda nueva.

Los imports dependientes de Raspberry se hacen al instanciar/arrancar cada
driver, por lo que importar este modulo en Windows sigue siendo seguro.
"""

import math
import threading
import time
from typing import Callable, Dict, NamedTuple, Optional, Tuple


class TramaPico(NamedTuple):
    """Trama de telemetria completa tal y como la emite la Pico 2."""

    yaw: float
    color: Optional[str]
    watchdog: Optional[str]
    ultrasonido_mm: Optional[float]


class EnlacePicoNuevo:
    """USB CDC con heading, color de piso, ultrasonido y edad de telemetria."""

    def __init__(self, puerto: str, baudrate: int = 115200, timeout_s: float = 0.5):
        import serial

        self._serial_mod = serial
        self._ser = serial.Serial(puerto, baudrate=baudrate, timeout=0.05)
        self._timeout_s = float(timeout_s)
        self._lock = threading.Lock()
        self._yaw_crudo = 0.0
        self._cero_yaw = None
        self._deriva_deg_s = 0.0
        self._t_deriva = 0.0
        self._color_piso = "DESCONOCIDO"
        self._ultrasonido_mm: Optional[float] = None
        self._watchdog_comando = None
        self._t_telemetria = 0.0
        self._corriendo = True
        self._hilo = threading.Thread(target=self._leer, name="pico-ronda-nueva", daemon=True)
        self._hilo.start()

    @staticmethod
    def parsear_telemetria(linea: str) -> Optional[Tuple[float, Optional[str]]]:
        """Parser historico; conserva exactamente el retorno ``(yaw, color)``."""

        extendida = EnlacePicoNuevo.parsear_telemetria_extendida(linea)
        if extendida is None:
            return None
        yaw, color, _watchdog = extendida
        return yaw, color

    @staticmethod
    def parsear_telemetria_extendida(
        linea: str,
    ) -> Optional[Tuple[float, Optional[str], Optional[str]]]:
        """Devuelve yaw, color y estado anunciado del watchdog de comandos.

        ``watchdog`` es ``None`` para firmware historico, ``OK``/``STOP`` para
        el firmware seguro e ``INVALIDO`` si la trama anuncia otro valor. Un
        valor invalido no inutiliza la IMU, pero nunca permite armar motores.

        Conserva a proposito la tupla de tres campos: es el contrato que ya
        usan las pruebas y el resto del arranque. El campo nuevo del
        ultrasonido se lee en :meth:`parsear_telemetria_completa`.
        """

        trama = EnlacePicoNuevo.parsear_telemetria_completa(linea)
        if trama is None:
            return None
        return trama.yaw, trama.color, trama.watchdog

    @staticmethod
    def parsear_telemetria_completa(linea: str) -> Optional[TramaPico]:
        """Lee la trama entera, incluido el ultrasonido trasero (``US:``).

        ``ultrasonido_mm`` es ``None`` cuando el firmware no anuncia el campo
        (version anterior), cuando el sensor no vio eco (la Pico manda -1) o
        cuando el numero llega corrupto. Un valor ausente NUNCA se confunde
        con "camino libre": quien lo consume debe tratar ``None`` como falta
        de evidencia, no como distancia grande.

        Un ``US:`` ilegible no invalida la trama: la IMU y el watchdog son
        criticos para la ronda y el ultrasonido solo es una ayuda.
        """
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

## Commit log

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2026-07-08 Añadimos codigos de Calibracion HSV para la ronda cerrada y Arreglo del Codigo Principal de la pico
    [main.py]
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2026-07-20 docs: mejorar documentación técnica contra la rúbrica WRO-FE 2026 (30 pts)
    - Corrige desincronización README/código: centro de servo y límites de
    giro documentados (180/140/240) no coincidían con los valores vigentes
    en src/pico/main.py (90/70/115).
    - Reorganiza 3d-Models/: V1 (impreso 3D, archivado) vs Chasis-LEGO-V2/
    (chasis actual, con archivo .io de BrickLink Studio y listado de las
    83 piezas para reproducibilidad).
    - Incorpora al README recursos que ya existían en el repo pero nunca se
    mostraban: diagrama de cableado, fotos de la placa perforada, catálogo
    de componentes con justificación de selección/ubicación y evidencia
    fotográfica de la calibración de áng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
    [Base_llanta.stl, Base_servo.stl, Chasis.stl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]
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2026-07-20 fix(close_round): corregir lado de evasión invertido y espacio de color de la cámara
    - EVADIR_POR_IZQUIERDA comparaba contra ROJO en vez de VERDE: el robot
    evadía por el lado contrario al reglamentario en ambos colores
    (regla WRO: rojo -> derecha, verde -> izquierda). Verificado contra
    la convención de signos usada en Open_round.py y en el firmware de
    la Pico (LIMITE_IZQ > CENTRO > LIMITE_DER).
    - cv2.cvtColor usaba COLOR_RGB2HSV sobre el frame de Picamera2, que en
    formato "RGB888" en realidad entrega bytes en orden BGR. Esto
    desalineaba los umbrales HSV calibrados con calibrar_hsv.py, que sí
    usa COLOR_BGR2HSV -- ahora ambos coinciden.
    [Close2_round.py]
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2026-07-20 fix(close_round): evitar crash de GPIO.cleanup() en doble Ctrl+C
    apagar_sistema() se re-ejecutaba si el usuario presionaba Ctrl+C dos
    veces seguidas (o si el signal handler se reentraba), dejando a
    GPIO.cleanup() operando sobre un handle ya cerrado y tumbando el
    script con lgpio.error: 'unknown handle'. Se agrega guardia de
    reentrada y se envuelve GPIO.cleanup() en try/except como defensa
    adicional.
    [Close2_round.py]
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2026-07-20 fix(close_round): subir el timeout de confirmacion DETECTADO->ESQUIVANDO de 0.3s a 1.2s
    El fallback por tiempo ganaba casi siempre antes que la confirmacion
    real de distancia via LiDAR (trk_confirmado+frontal<600 o frontal<400),
    haciendo que el robot se comprometiera a esquivar sin haber confirmado
    que el obstaculo estuviera realmente cerca. Ahora ese timeout queda
    como red de seguridad de ultimo recurso, no como el camino normal.
    [Close2_round.py]
2026-07-20 fix(close_round): dar mas tiempo/angulo a RECENTRANDO para converger de verdad
    En pista se registro Error heading=68.1 grados al salir de RECENTRANDO
    -> CARRERA, es decir, el estado se rindio por timeout (1.5s) sin haber
    corregido el rumbo. El robot volvia a CARRERA muy desalineado y eso
    disparaba EMERGENCIA COLISION INMINENTE casi de inmediato, entrando en
    un ciclo de RETROCEDIENDO/FORZANDO_GIRO que empeoraba cada vuelta
    (distancias de emergencia decrecientes en el log real).
    - TIMEOUT_RECENTRANDO sube de 1.5s a 3.0s.
    - El limite de giro sube de +-25 a +-MAX_ANGULO_EVASION (32), igual
    que el resto de la maniobra de evasion, en vez de un valor propio
    mas conservador que ya estaba satura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
    [Close2_round.py]
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2026-07-21 fix: implementar modo Inercial real (sostener ultima pared valida)
    El README (seccion 5.3-A) documenta que al perder la lectura de una
    pared el software 'congela el ultimo angulo de giro valido', pero el
    codigo real simplemente saltaba a un valor fijo (2000mm) cada vez que
    dist_derecha_min/dist_izquierda_min superaba 4000mm -- sin sostener
    nada. Eso puede causar un giro brusco justo cuando una pared se pierde
    momentaneamente (comun en curvas cerradas).
    Ahora ambos scripts (Open_round.py y Close2_round.py) sostienen el
    ultimo valor valido conocido de cada lado en vez de usar el valor fijo,
    acercando el comportamiento real a lo documentado.
    [Close2_round.py]
2026-07-21 fix(close_round): no aplicar el frenado progresivo fuera de CARRERA
    factor_frenado se multiplicaba sobre velocidad_base en TODOS los
    estados excepto RETROCEDIENDO/FORZANDO_GIRO. Dos problemas reales:
    - En DETECTADO ya se aplicaba una vez al calcular velocidad_base
    (VELOCIDAD_CRUCERO * factor_frenado); la segunda multiplicacion al
    final elevaba el frenado al cuadrado, deteniendo al robot antes de
    lo calibrado.
    - En ESQUIVANDO/PASANDO/RECENTRANDO la velocidad ya era fija
    (VELOCIDAD_EVASION) y no debia frenarse por 'frontal', que durante
    estos estados se mide con el sector frontal ensanchado (para no
    perder el cluster del obstaculo) -- es decir, reflejaba la cercania
    del propio p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
    [Close2_round.py]
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2026-07-22 docs+chore: limpiar comentarios sueltos y arreglar enlace roto del README
    - vision.py: docstring de modulo comprimido a 3 lineas.
    - src/pico/main.py: comentarios en segunda persona ("tus limites",
    "tu CENTRO") reescritos en tono neutral.
    - calibrar_hsv.py: comentarios estilo bitacora ("NUEVO", "el ruido que
    viste") reescritos como comentarios normales.
    - src/pi3B/ronda_cerrada/legacy/README.md: el enlace al README
    principal apuntaba a src/README.md (inexistente) porque le faltaba
    un nivel `../` desde que legacy/ se anido dentro de ronda_cerrada/.
    Corregido a la ruta real.
    - README.md: agregada seccion de Licencia (MIT) y dependencias de
    terceros -- no estaba mencionada en ningun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
    [main.py]
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2026-07-27 feat(pi3B): instrumentar metricas cuantitativas de rendimiento en pista
    Agrega comun/registro_metricas.py (logger CSV por corrida: fase, estado,
    heading, error lateral, angulo, velocidad) integrado en ronda_abierta.py
    y ronda_cerrada.py, mas calibracion/analizar_log.py para resumir esos
    logs en metricas agregadas (error lateral promedio/maximo, saturacion
    del servo, eventos de emergencia). Reemplaza la validacion puramente
    observacional del ajuste de KP_LATERAL/KD_ESTABILIDAD descrita en la
    seccion 5.4 del README.
    [ronda_abierta.py]
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2026-08-02 fix(ronda_abierta): volver a la version autocontenida validada en pista
    La version que reutilizaba comun/ (lidar_driver, lidar_geometria,
    enlace_pico) no funciono en la prueba de campo. Se reemplaza por la
    implementacion autocontenida que si tiene todo el flujo validado
    (centrado proporcional + deteccion de parqueo por firma de pared),
    con los comentarios limpios y sin emojis en los prints.
    - Se agrega el registro de metricas (comun/registro_metricas.py) que
    ya usa ronda_cerrada.py, para mantener paridad entre ambas rondas y
    poder sacar conclusiones cuantitativas de cada corrida (error
    lateral, saturacion del servo) en vez de solo observacion.
    - README y INSTALACION.md actualizados: r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
    [ronda_abierta.py]
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2026-08-27 fix(ronda_cerrada): enderezar el frame, la camara va montada invertida
    El modulo de camara esta montado boca abajo en el chasis. camara_driver
    entregaba el frame tal cual salia de picamera2, asi que vision.py lo
    procesaba de cabeza. Verificado capturando el frame crudo: los postes
    aparecen colgando del techo, con el piso arriba y sus reflejos por
    encima.
    Dos consecuencias, una latente y otra activa:
    - poste_cx queda espejado. Hoy no se nota porque vision.py no expone
    ese dato y nadie lo lee, pero en cuanto se use para apuntar la
    evasion mandaria al robot por el lado contrario del poste.
    - el filtro cy < 180 se invierte. Con el piso en la parte alta del
    array, el centroide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
    [camara_driver.py]
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2026-08-28 feat(pi3B): versionar las 8 herramientas de diagnostico que solo vivian en la Pi
    Los scripts de diagnostico y calibracion de las jornadas del 27 y 28 de
    agosto estaban unicamente en ~/ronda_cerrada_test/ de la Raspberry, fuera
    de git. Varios los cita el codigo de carrera ya commiteado como la forma
    correcta de reajustar una constante -- navegacion.py dice "correr
    calib_fov.py y sustituir estos dos numeros" -- asi que sin ellos esas
    instrucciones apuntan a nada.
    Se agrupan en herramientas/ y no en la antigua calibracion/, que el equipo
    elimino a proposito en fb22298b; lo que aquella contenia sigue recuperable
    de la historia. deploy.sh no las copia porque no son parte del despliegue
    de compet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
    [calib_fov.py, medir_velocidad.py]
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2026-08-31 feat(pico): watchdog autonomo de 500 ms y parser acotado de consignas
    La auditoria del diagrama de arquitectura confirmo que el fail-safe de
    enlace nunca existio: si la Pi moria a mitad de carrera, la Pico seguia
    aplicando la ultima consigna sin limite. protocolo_seguro.py valida cada
    trama (campos, rangos, tipos) y modela el vencimiento del watchdog como
    funcion pura testeable en laptop; main.py frena y centra tras 500 ms sin
    consigna valida y anuncia WD:OK/STOP en la telemetria para que la Pi
    pueda exigir el handshake antes de armar la traccion. Verificado en la
    Pico real el 2026-08-29: WD:STOP 465 ms despues de cortar el heartbeat.
    [main.py, protocolo_seguro.py]
2026-08-31 feat(ronda_nueva): modelos, configuracion con barrera y capa de hardware
    Base de la reescritura de la ronda con obstaculos. Toda calibracion viva
    (optica, extrinsecas, HSV, latencias, umbrales de parqueo) sale del codigo
    y entra a configuracion.json con tres banderas de aprobacion fisica; la
    barrera impide habilitar movimiento con calibraciones pendientes, para que
    un despliegue a medio calibrar no pueda mover el robot por accidente.
    hardware.py aisla GPIO/serial detras de interfaces y exige observar WD:OK
    de la Pico antes de armar; sincronizacion.py conserva pocos timestamps y
    rechaza pares camara-LiDAR demasiado viejos, corrigiendo la debilidad que
    el subcampeon 2025 (KMIDS) dejo abierta a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
    [config.py, hardware.py, modelos.py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]
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2026-08-31 fix(ronda_nueva): sin pared confiable el timon endereza por rumbo, no se congela
    Las tres corridas de pista del 2026-08-31 (120547, 122058, 123251)
    terminaron en FAILED. En las dos primeras la firma es identica: el robot
    sale del sobrepaso pegado a la pared derecha (138 mm), corrige fuerte a
    la izquierda y cruza el carril hasta +33 grados; con esa vista oblicua la
    calidad del ajuste de pared cae bajo wall_min_quality y _angulo_pared
    devolvia 0.0 fijo, asi que RECENTER mantuvo el timon recto 5 s derivando
    en diagonal hasta "timeout de reincorporacion" (19 de 49 ciclos con
    angulo 0.00 exacto en el CSV).
    El fallback nuevo usa lo unico que sigue disponible sin paredes: la IMU y
    el conteo de esq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
    [control_ruta.py]
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2026-08-31 feat(ronda_nueva): maniobra de esquina en tres tiempos para el radio real
    El radio minimo medido en pista es de unos 600 mm y una esquina de carril
    de 1000 mm necesita 400-500: el arco no cabe y el giro de una sola pasada
    termina empujando contra la pared hasta el timeout. La maniobra alterna
    avance y reversa dentro del propio estado TURN, sin estados nuevos en la
    FSM ni cambios en el resto del recorrido.
    El detalle que la hace funcionar es el signo del volante. Con Ackermann la
    rotacion es omega = v*tan(delta)/L, asi que al retroceder hace falta el
    volante al lado CONTRARIO para que el morro siga rotando hacia el mismo
    lado; usar el mismo angulo que en avance desharia el giro. Hay una prue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
    [control_ruta.py]
2026-08-31 fix(ronda_nueva): sostener el tramo de reversa, la trasera es bimodal en la esquina
    La primera prueba en pista de la maniobra (corrida 145409) completo dos
    esquinas, pero los tramos 2 al 6 fueron oscilacion pura: conmutaba entre
    avance y reversa cada 0,2 s y el robot no llegaba a desplazarse porque el
    slew de velocidad nunca alcanzaba el PWM pedido.
    La causa no es ruido del sensor. En la esquina el sector trasero cruza la
    arista entre dos paredes y la lectura alterna entre dos valores reales,
    258 y 690 mm, los dos con trasera_valida y cobertura por encima de 0,97.
    El umbral de confort de 300 mm caia justo entre ambos modos, asi que cada
    barrido cambiaba de opinion.
    Ahora un tramo empezado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
    [control_ruta.py]
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2026-08-31 fix(ronda_nueva): la pared endereza durante la evasion, no elige el lado
    Diagnostico del equipo, confirmado con los CSV: el lado por el que se
    rebasa un pilar lo acababa decidiendo el LiDAR y no el color. En la
    corrida 145857 la guardia de pared llego a pesar 0,94 sobre el mando y el
    robot giraba a -18 grados, hacia el propio pilar que esquivaba, mientras
    la pared izquierda se le acercaba a 131 mm.
    No era un caso extremo sino la regla. Con un carril de 1000 mm, un pilar
    de 50 y un robot de 125, rebasar por un lado deja unos 175 mm a la pared:
    siempre por debajo de wall_guard_start_mm, asi que la guardia intervenia
    en toda evasion normal.
    La causa concreta es el termino lateral del protecto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
    [control_ruta.py]
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2026-08-31 fix(ronda_nueva): el recentrado se confirma con laterales, no con la calidad
    Estar centrado es una afirmacion sobre distancias medidas, no sobre lo
    bien que se ajusto la recta de la pared, y confundir las dos cosas hacia
    inconfirmable el recentrado justo cuando mas falta hacia. En las corridas
    152111 y 152413 el robot llego a 108 mm de error lateral, holgadamente
    dentro de la tolerancia de 150, y aun asi agoto el timeout de
    reincorporacion: la calidad del ajuste habia caido a 0,21 tras rebasar el
    pilar y el criterio exigia 0,30. Se quedaba centrado, quieto y fallando.
    Ahora el centrado lo deciden las laterales validas y el error medido. La
    calidad sigue gobernando el mando en _angulo_pared,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
    [control_ruta.py]
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2026-08-31 fix(geometria): el LiDAR va al ras del morro, medido con regla
    geometria_robot.py marcaba LIDAR_X y LIDAR_Y como [ESTIMADO] por
    fotogrametria sobre las v-photos, con +-10mm de incertidumbre en x, y
    pedia explicitamente sustituirlos por una medicion con regla. Hecha esa
    medicion: el LiDAR esta al ras del borde delantero y el perimetro queda a
    45 mm por la derecha y 61 por la izquierda.
    LIDAR_X 128 -> 162 mm (error de 34, mas del triple de la
    incertidumbre que se le habia asignado)
    LIDAR_Y -4 -> +8 mm (cae a la derecha del eje, no a la izquierda)
    Los dos valores pasan a derivarse de las distancias medidas en vez de
    escribirse a mano, y se anota ANCHO_E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
    [geometria_robot.py]
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2026-08-31 fix(ronda_nueva): soltar el pilar que no se puede reasociar, no esperarlo parado
    Repetida tres veces la misma configuracion desde la misma salida: 6, 2 y 3
    esquinas. Las dos que menos duraron fallaron por lo mismo, y es un punto
    muerto: al perder el track bloqueado el robot se para "para reasociar",
    pero la reasociacion exige un track confirmado, la confirmacion exige
    color, y el color no vuelve mientras el pilar siga dentro del punto ciego
    de 251 mm. Quieto no se sale de ahi nunca. Las dos corridas agotaron
    parados los 9,7 s del timeout de evasion y terminaron en FAILED.
    Ahora la espera tiene un margen corto (obstacle_relock_timeout_s, 0,8 s) y
    si no consigue reasociar suelta el pilar y de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
    [control_ruta.py]
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2026-09-01 fix(percepcion): el mecanismo de direccion no es una pared lateral
    Al girar, la rueda entra en el barrido lateral del LiDAR y aparece por
    debajo del perimetro del robot, que esta a 61 mm por la izquierda y 45 por
    la derecha del eje. Medido sobre las corridas del 2026-08-31 y 09-01: 101
    lecturas laterales imposibles a la izquierda, con el servo mediano en +17
    grados, y 90 a la derecha con -8. La correlacion entre el lado imposible y
    el lado hacia el que gira el servo no deja mucho margen de duda.
    Cada una de esas lecturas podia disparar una emergencia falsa, y varias lo
    hicieron: en la corrida 124629 la lateral izquierda marco 51, 50 y 49 mm
    en tres episodios seguidos de RECOVERY, con el rob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
    [percepcion_lidar.py]
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2026-09-01 fix(percepcion): el eco de la rueda se aleja segun cuanto gire el volante
    El filtro anterior reutilizaba wall_side_min_mm, 80 mm, y se quedo corto.
    Con el servo a +17 grados el eco de la direccion aparecia a 49-51 mm, pero
    con el volante al tope, +25, salta a 91-107 y pasaba el filtro. Eso mato la
    corrida 130404: tres RECOVERY seguidos en mitad de un giro con la lateral
    izquierda marcando 91-107 mm y nada al lado.
    El umbral del fallback pasa a ser su propio parametro,
    lateral_fallback_min_mm=160, separado del que filtra puntos para ajustar
    rectas. Subirlo es seguro porque una pared de verdad a esa distancia deja
    puntos de sobra y se ajusta como recta: al minimo crudo solo se cae cuando
    lo q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
    [percepcion_lidar.py]
2026-09-01 fix(percepcion): rechazar el salto lateral que la fisica no permite
    Filtrar por distancia no bastaba. Con el volante al tope, el eco de la
    rueda aparece a 90-107 mm, supera wall_side_min_mm y llega a ajustarse
    como recta lateral: a partir de ahi es indistinguible de una pared para
    cualquier umbral de distancia, y por eso el filtro anterior no lo veia.
    La continuidad si lo distingue. En la corrida 131112 la lateral izquierda
    salta de 832 a 101 mm en un solo barrido de 0,1 s, cuando a 22 PWM el
    robot avanza 9 mm. No es que apareciera una pared: es que el LiDAR se vio
    a si mismo. Ese salto disparo tres emergencias seguidas.
    Solo se vigila el acercamiento. Que una lateral se aleje de golpe es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
    [percepcion_lidar.py]
2026-09-01 Revert "fix(percepcion): rechazar el salto lateral que la fisica no permite"
    This reverts commit a73043934efc4544d253506e1bbb6ad9ee283521.
    [percepcion_lidar.py]
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2026-09-01 fix(percepcion): descartar la pared imposible tambien si viene de una recta
    El filtro anterior solo miraba el minimo crudo del sector, con lo que una
    recta ajustada sobre esos mismos puntos se colaba entera. En la corrida
    134145 la lateral izquierda alternaba, en ciclos consecutivos, 709 mm con
    calidad 0,83 y 58 mm con calidad 0,23: el segundo valor venia de un ajuste
    y disparaba la emergencia. Ochenta y nueve recuperaciones, cero esquinas.
    Una pared mas cercana que el propio chasis no existe, venga del minimo o
    de una recta: el perimetro esta a 61 mm por la izquierda y 45 por la
    derecha del eje del LiDAR. El descarte deja de depender de si hubo ajuste.
    Se aprovecha para dejar constancia d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
    [percepcion_lidar.py]
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2026-09-01 fix(ronda_nueva): sin reversa disponible, la esquina sigue girando
    Tercer punto muerto del mismo tipo, y el patron ya es reconocible: la
    maniobra se paraba a esperar una trasera fiable que puede no llegar nunca.
    En la corrida 144939 el robot quedo 14 s inmovil con el heading congelado
    en +430 hasta que lo mato el timeout de esquina, teniendo 1093 mm libres a
    la izquierda y 750 a la derecha.
    Sin reversa disponible queda seguir girando hacia delante, que es lo que
    se hacia antes de existir la maniobra en tres tiempos. La velocidad la
    modera _con_frenado segun el frente y, si llega al limite, la emergencia
    toma el mando: cualquiera de las dos cosas avanza. Estar quieto no.
    El arreglo del rece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
    [control_ruta.py]
2026-09-01 revert: volver al estado que mas aguanto en pista
    Deja el codigo en el punto con el que se midio la corrida 144939: 3
    esquinas en 111,9 s, las tres reincorporaciones verificadas, 34
    emergencias y ninguna lectura lateral imposible.
    Frente al estado de 5 esquinas cierra una menos, pero dura mas del doble y
    sobre todo es repetible, que era lo que faltaba: las dos corridas previas
    con esta misma base dieron 3 esquinas en 45 y 46 s con 25 y 23
    emergencias.
    Conserva el descarte de la pared imposible aunque venga de una recta
    ajustada, y la tolerancia de recentrado a 250 mm con timeout de 4,0 s.
    Queda fuera el arreglo del punto muerto del K-turn, que subio las
    emergencias de 34 a 145 aunque el pu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
    [control_ruta.py]
2026-09-01 docs(ronda_nueva): serie de cinco corridas, la primera medida fiable
    Cinco corridas seguidas sin tocar nada: 7, 6, 8, 4 y 6 esquinas. Mediana 6
    -vuelta y media-, rango 4-8, y tres de las cinco llegan al final de la
    ventana de 180 s. La mejor hizo 8 esquinas, o sea dos vueltas completas,
    con 12 pilares rebasados y sin fallar.
    Lo que la serie corrige del resto de la sesion: la corrida de 5 esquinas
    que tomamos por la mejor y la de 1 que nos hizo revertir caen las dos
    dentro de este rango. Ninguna medía el codigo, y sobre ellas se tomaron
    decisiones.
    Dos hallazgos que solo aparecen con varias corridas. Las emergencias no
    predicen nada: 7 esquinas con 11 y 6 esquinas con 172, y la corrida con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
    [ronda_nueva_20260901_152424_8esquinas.csv, serie5_20260901_run1.csv, serie5_20260901_run2.csv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]
2026-09-01 fix(ronda_nueva): mezclar pared y rumbo en vez de conmutar, y aflojar la salida de recuperacion
    Los dos unicos fallos de la serie de cinco, y ninguno era de percepcion.
    El recentrado oscilaba. Conmutar de golpe entre el centrado de pared y el
    rumbo del carril hace bailar el timon cuando la calidad del ajuste ronda
    el umbral, que es exactamente lo que ocurre reincorporandose tras un
    pilar: en el episodio final de la corrida 154617 la calidad alternaba
    entre 0,21 y 0,83 barrido a barrido y el robot se paso el centro dos veces
    sin llegar a confirmarlo. Solo 1 de 65 ciclos bajo de la tolerancia, y
    murio por timeout oscilando alrededor del sitio correcto. Ahora los dos
    controles se mezclan en un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
    [control_ruta.py]
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2026-09-02 feat(control_ruta): reactividad de evasion y ultrasonido hacia el parqueo
    Evasion. El slew de crucero son 6 grados por barrido: a 10 Hz eso son cinco
    barridos -- medio segundo, 8 cm a 40 PWM -- para llegar al tope de
    direccion. Contra un pilar que aparece a menos de un metro esa rampa se
    come el margen de maniobra: el robot pide el angulo correcto y llega tarde.
    Se le da a la evasion su propio slew (avoid_steering_slew_deg_per_scan,
    18 grados), mas suelto que el de carril y mas contenido que el de esquina.
    Y la ganancia de persecucion pasa a depender de la distancia
    (obstacle_pursuit_kp_near 1,6 entre 950 y 320 mm). Con ganancia unica hay
    que elegir: si sirve de lejos, de cerca se queda cor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
    [control_ruta.py]
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2026-09-02 fix(control_ruta): el sobrepaso sale por geometria, no por cronometro
    obstacle_cleared_y_mm no ha decidido NUNCA. Repasando los 74 episodios de
    AVOID_PASS de las ocho corridas del 01-09, las 74 salidas fueron por la red
    de seguridad de distancia muerta, asi que el sobrepaso duraba siempre lo
    mismo -3,28 s de media- sin importar la geometria del pilar ni si el LiDAR
    lo estaba viendo. Evadir se lleva entre el 45% y el 52% de la ronda.
    El criterio era inalcanzable por construccion. El pilar deja de existir para
    la percepcion a una mediana de 216 mm (143 perdidas medidas, p75 249): un
    poste de 100 mm subtiende 23 grados a 250 mm y es_cluster_obstaculo acota el
    arco a 15. Pedir verlo 280 mm POR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
    [control_ruta.py]
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

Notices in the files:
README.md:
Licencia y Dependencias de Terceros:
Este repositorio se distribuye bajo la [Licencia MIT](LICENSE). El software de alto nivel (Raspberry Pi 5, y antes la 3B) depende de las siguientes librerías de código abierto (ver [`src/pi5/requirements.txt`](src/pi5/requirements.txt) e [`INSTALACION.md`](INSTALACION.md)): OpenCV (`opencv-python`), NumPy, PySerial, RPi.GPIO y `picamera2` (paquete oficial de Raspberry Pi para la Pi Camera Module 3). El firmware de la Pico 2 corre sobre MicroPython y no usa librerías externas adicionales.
